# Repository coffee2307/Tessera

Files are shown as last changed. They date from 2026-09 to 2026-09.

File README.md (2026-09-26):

# Tessera

## English

### Overview

Tessera is a personal precision motion platform for compact XYZ positioning, alignment, probing, microscopy, and small-scale automation. It combines a parallel-kinematic mechanical structure with closed-loop stepper control, rotary encoders, motion planning, and a serial command interface.

The design aims to provide a low-cost and reproducible motion platform with practical sub-micron positioning capability for laboratory, research, and prototyping workflows. The software stack is divided between embedded firmware and a Python control layer so the hardware can be configured, calibrated, and operated through a clean API.

### Main features

- 3-axis XYZ motion using a parallel-kinematic mechanism
- Closed-loop control with stepper motors and encoder feedback
- Sub-micron positioning for precision alignment and inspection work
- USB serial communication with G-code-style command handling
- Firmware-side path planning and interpolation for smooth motion
- Homing and calibration routines for repeatable setup
- External tool control support for device actuation
- Open hardware and software structure for experimentation and customization

### Project architecture

The repository is organized into several functional domains:

- Mechanical design: CAD and manufacturing files in thiet_ke_co_khi/
- Electronics: PCB and schematics in dien_tu/
- Firmware: embedded C++ controller in phan_mem_nhung/bo_dieu_khien_chuyen_dong_rp/
- Python API: device communication and helper scripts in phan_mem/api_python/
- Documentation: build notes, setup guidance, and BOM in tai_lieu/

### Repository structure

- thiet_ke_co_khi/ - CAD models, assemblies, and mechanical parts
- dien_tu/ - KiCad PCB schematics and board files
- phan_mem_nhung/bo_dieu_khien_chuyen_dong_rp/ - firmware project and embedded source code
- phan_mem_nhung/bo_dieu_khien_chuyen_dong_rp/src/ - C++ firmware implementation
- phan_mem/api_python/ - Python API, utilities, and usage examples
- tai_lieu/ - technical documentation, setup references, and BOM

### Mechanical design

The mechanical platform uses a parallel geometry to achieve compact motion with high stiffness and repeatability. The structure is designed around a three-axis motion system, with linkage and ball-joint behavior tuned for controlled end-effector motion. Mechanical files are stored in the FreeCAD-based construction package and are intended to be modified and adapted for custom builds.

### Electronics design

The electronics layer includes the control board and related hardware configuration. The system relies on stepper drives, encoder interfaces, logic/control circuitry, and power distribution arranged to support the motion controller and its real-time feedback loops. These design files are located under dien_tu/ and provide the hardware reference for the embedded controller.

### Firmware architecture

The firmware is written in C++ and is organized around the real-time device controller. It implements the logic required for motion execution, servo regulation, calibration, and serial communication.

Core firmware responsibilities:

- Kinematic model: workspace and geometry calculations
- Motion controller: command execution and trajectory planning
- Servo control: feedback loops and actuator regulation
- Homing and calibration: initialization and system alignment
- Communication layer: command parsing and response handling

Main firmware components:

- phan_mem_nhung/bo_dieu_khien_chuyen_dong_rp/src/main.cpp - startup and system initialization
- phan_mem_nhung/bo_dieu_khien_chuyen_dong_rp/src/robot.cpp - coordinated device behavior
- phan_mem_nhung/bo_dieu_khien_chuyen_dong_rp/src/dieu_khien_chuyen_dong/ - path planning and movement logic
- phan_mem_nhung/bo_dieu_khien_chuyen_dong_rp/src/dieu_khien_servo/ - closed-loop control loops
- phan_mem_nhung/bo_dieu_khien_chuyen_dong_rp/src/mo_hinh_dong_hoc/ - geometry and kinematic calculations
- phan_mem_nhung/bo_dieu_khien_chuyen_dong_rp/src/hw_config.h - hardware configuration such as pin map and motor settings

### Control and communication model

The system is intended to be commanded over a serial connection. The firmware accepts motion and control instructions and returns status information to the host. This makes it compatible with higher-level control software, automation workflows, and Python-based experimentation.

Typical capabilities include:

- moving to target coordinates
- homing the axes
- enabling or disabling motors
- querying device state
- calibrating joints
- setting tool output values

### Python API

The Python layer wraps the serial connection and exposes a simplified interface for controlling the platform. It is intended to reduce the amount of low-level command handling required when testing motion, calibration, or automated procedures.

Relevant Python files:

- phan_mem/api_python/tessera_api.py
- phan_mem/api_python/vi_du_su_dung.py
- phan_mem/api_python/ve_bieu_do_hieu_chuan.py

The API generally supports:

- connection management
- homing and motion commands
- calibration routines
- device status queries
- asynchronous logging and communication feedback

### Quick start

1. Review the mechanical and electrical documentation in tai_lieu/.
2. Build the hardware according to the project instructions.
3. Adjust the hardware configuration in phan_mem_nhung/bo_dieu_khien_chuyen_dong_rp/src/hw_config.h.
4. Flash the firmware using PlatformIO.
5. Connect the device over serial.
6. Use the Python API or a terminal client to home the platform and begin motion testing.

### Example usage

```python
from phan_mem.api_python.tessera_api import TesseraInterface

api = TesseraInterface(show_communication=True, show_log_messages=True)
api.connect('/dev/ttyACM0')

api.home()
api.move_to(0.0, 0.0, 0.0, f=10)
api.move_to(3.1, 4.1, 5.9, f=26)
api.wait_for_stop()
```

### Notes

- The project is designed for open experimentation and reproducible builds.
- The firmware and mechanical system are the primary technical foundations of the repository.
- The Python layer is meant to simplify communication, testing, calibration, and operational workflows.

---

## Tiếng Việt

### Tổng quan

Tessera là một nền tảng chuyển động XYZ kiểu compact, mã nguồn mở, được thiết kế cho các nhiệm vụ căn chỉnh, dò kiểm tra, kính hiển vi và tự động hóa quy mô nhỏ. Hệ thống này kết hợp cơ cấu cơ khí song song, bộ điều khiển động cơ vòng kín, và giao diện điều khiển thân thiện với Python để tạo ra một giải pháp di chuyển chính xác với chi phí thấp và khả năng tái tạo tốt.

### Tính năng chính

- Chuyển động 3 trục XYZ theo cơ cấu song song
- Điều khiển vòng kín bằng động cơ bước và bộ mã hóa quay
- Khả năng định vị ở mức dưới micromet cho công việc căn chỉnh và kiểm tra
- Giao tiếp qua cổng serial USB với lệnh kiểu G-code
- Lập lịch đường đi và nội suy chuyển động ở phần firmware
- Chức năng homing và hiệu chuẩn để khởi tạo hệ thống lặp lại
- Hỗ trợ điều khiển đầu công cụ ngoài để kích hoạt thiết bị phụ trợ
- Cấu trúc phần cứng và phần mềm mở, dễ tùy biến và thử nghiệm

### Kiến trúc dự án

Kho mã nguồn được tổ chức theo các tầng chức năng chính:

- Thiết kế cơ khí: mô hình CAD và file gia công trong thiet_ke_co_khi/
- Điện tử: bo mạch và sơ đồ trong dien_tu/
- Firmware: bộ điều khiển nhúng C++ trong phan_mem_nhung/bo_dieu_khien_chuyen_dong_rp/
- Python API: giao tiếp thiết bị và script hỗ trợ trong phan_mem/api_python/
- Tài liệu: hướng dẫn xây dựng, thiết lập và BOM trong tai_lieu/

### Cấu trúc thư mục

- thiet_ke_co_khi/ - mô hình CAD, bộ lắp ráp và linh kiện cơ khí
- dien_tu/ - file sơ đồ PCB KiCad và board layout
- phan_mem_nhung/bo_dieu_khien_chuyen_dong_rp/ - mã nguồn firmware và dự án PlatformIO
- phan_mem_nhung/bo_dieu_khien_chuyen_dong_rp/src/ - phần triển khai firmware C++
- phan_mem/api_python/ - API Python, tiện ích và ví dụ sử dụng
- tai_lieu/ - tài liệu kỹ thuật, hướng dẫn lắp đặt và danh mục vật tư

### Thiết kế cơ khí

Cấu trúc cơ khí sử dụng hình học song song để đạt được chuyển động nhỏ gọn, cứng vững và lặp lại tốt. Hệ thống được thiết kế theo mô hình 3 trục với các liên kết và khớp cầu nhằm kiểm soát chuyển động của đầu công cụ. Các file thiết kế cơ khí nằm trong gói CAD FreeCAD và có thể được chỉnh sửa để phù hợp với từng bản dựng cụ thể.

### Thiết kế điện tử

Lớp điện tử bao gồm bo mạch điều khiển và cấu hình phần cứng tương ứng. Hệ thống dùng động cơ bước, giao diện mã hóa, mạch điều khiển logic và phân phối nguồn để hỗ trợ bộ điều khiển chuyển động và vòng phản hồi thời gian thực. Các file này nằm trong dien_tu/ và là tài liệu tham khảo cho phần firmware.

### Kiến trúc firmware

Firmware được viết bằng C++ và tổ chức theo mô hình bộ điều khiển thiết bị thời gian thực. Nó xử lý các nhiệm vụ cần thiết cho việc thực thi chuyển động, điều khiển servo, hiệu chuẩn và giao tiếp serial.

Các trách nhiệm chính của firmware:

- Mô hình động học: tính toán không gian làm việc và hình học
- Bộ điều khiển chuyển động: thực thi lệnh và lập kế hoạch quỹ đạo
- Điều khiển servo: vòng lặp phản hồi và điều chỉnh actuator
- Homing và hiệu chuẩn: khởi tạo và căn chỉnh hệ thống
- Lớp giao tiếp: phân tích lệnh và xử lý phản hồi

Những thành phần quan trọng:

- phan_mem_nhung/bo_dieu_khien_chuyen_dong_rp/src/main.cpp - khởi động và khởi tạo hệ thống
- phan_mem_nhung/bo_dieu_khien_chuyen_dong_rp/src/robot.cpp - hành vi tổng hợp của thiết bị
- phan_mem_nhung/bo_dieu_khien_chuyen_dong_rp/src/dieu_khien_chuyen_dong/ - logic lập kế hoạch đường đi
- phan_mem_nhung/bo_dieu_khien_chuyen_dong_rp/src/dieu_khien_servo/ - vòng lặp điều khiển đóng
- phan_mem_nhung/bo_dieu_khien_chuyen_dong_rp/src/mo_hinh_dong_hoc/ - tính toán hình học và động học
- phan_mem_nhung/bo_dieu_khien_chuyen_dong_rp/src/hw_config.h - cấu hình phần cứng như chân GPIO và cài đặt motor

### Mô hình điều khiển và truyền thông

Hệ thống được thiết kế để điều khiển qua kết nối serial. Firmware nhận lệnh di chuyển và điều khiển từ máy tính và gửi thông tin trạng thái trở lại. Điều này giúp hệ thống tương thích với phần mềm điều khiển cấp cao, quy trình tự động hóa và thử nghiệm dựa trên Python.

Các khả năng điển hình gồm:

- di chuyển đến tọa độ mục tiêu
- homing trục
- bật/tắt động cơ
- truy vấn trạng thái thiết bị
- hiệu chuẩn joint
- đặt giá trị đầu ra của công cụ

### Python API

Lớp Python đóng gói kết nối serial và cung cấp giao diện đơn giản để điều khiển hệ thống. Mục tiêu là giảm khối lượng xử lý lệnh mức thấp khi kiểm tra chuyển động, hiệu chuẩn hoặc quy trình tự động hóa.

Các file Python quan trọng:

- phan_mem/api_python/tessera_api.py
- phan_mem/api_python/vi_du_su_dung.py
- phan_mem/api_python/ve_bieu_do_hieu_chuan.py

API thường hỗ trợ:

- quản lý kết nối
- lệnh homing và di chuyển
- chức năng hiệu chuẩn
- truy vấn trạng thái thiết bị
- log giao tiếp và phản hồi liên tục

### Bắt đầu nhanh

1. Đọc tài liệu cơ khí và điện tử trong tai_lieu/
2. Lắp ráp phần cứng theo hướng dẫn của dự án
3. Điều chỉnh cấu hình phần cứng trong phan_mem_nhung/bo_dieu_khien_chuyen_dong_rp/src/hw_config.h
4. Nạp firmware bằng PlatformIO
5. Kết nối thiết bị qua serial
6. Dùng Python API hoặc client terminal để homing trục và bắt đầu kiểm tra chuyển động

### Ví dụ sử dụng

```python
from phan_mem.api_python.tessera_api import TesseraInterface

api = TesseraInterface(show_communication=True, show_log_messages=True)
api.connect('/dev/ttyACM0')

api.home()
api.move_to(0.0, 0.0, 0.0, f=10)
api.move_to(3.1, 4.1, 5.9, f=26)
api.wait_for_stop()
```

### Lưu ý

- Dự án này thích hợp cho thử nghiệm mở và bản dựng có thể tái sản xuất.
- Firmware và hệ thống cơ khí là nền tảng kỹ thuật chính của kho mã nguồn.
- Lớp Python nhằm đơn giản hóa giao tiếp, thử nghiệm, hiệu chuẩn và quy trình vận hành.

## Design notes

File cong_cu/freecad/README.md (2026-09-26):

# Chỉnh sửa mô hình FreeCAD Tessera

## Chạy

- Trong VS Code, chọn **Terminal > Run Task > FreeCAD: Edit Tessera**.
- Hoặc mở PowerShell tại thư mục dự án và chạy:

```powershell
& ".\cong_cu\freecad\run_freecad.ps1"
```

Script được chạy bằng Python tích hợp trong FreeCAD, không cần cài thư viện FreeCAD bằng pip. Với đối tượng `App::Link`, FreeCAD cần chạy trong GUI để có `ViewObject`; `freecadcmd.exe` ở chế độ headless không thể đổi màu riêng cho Link. Khi đó, mở FreeCAD GUI, mở Python console và chạy:

```python
exec(compile(open(r"F:\Tessera\cong_cu\freecad\edit_tessera.py", "rb").read(), r"F:\Tessera\cong_cu\freecad\edit_tessera.py", "exec"))
```

## Tệp

- Tệp đầu vào: `thiet_ke_co_khi/bo_thao_tac_vi_mo/Assembly_MicroManipulator.FCStd`
- Bản sao lưu: `thiet_ke_co_khi/bo_thao_tac_vi_mo/Assembly_MicroManipulator.backup.FCStd`
- Tệp đầu ra: `thiet_ke_co_khi/bo_thao_tac_vi_mo/Assembly_MicroManipulator_edited.FCStd`

Bản sao lưu chỉ được tạo nếu chưa tồn tại. Tệp đầu vào không bị ghi đè.

## Tùy chỉnh

Để đổi đối tượng, sửa giá trị `TARGET_NAME` trong `edit_tessera.py`.
Để đổi màu, sửa `TARGET_COLOR` bằng ba giá trị RGB từ `0` đến `255`, được chuyển thành dạng số thực khi cần. Mặc định là vàng RGB `(255, 191, 0)`.

Tệp `.FCStd` là tệp mô hình nhị phân có cấu trúc riêng; không nên sửa trực tiếp bằng trình soạn thảo văn bản. Hãy chỉnh qua FreeCAD hoặc script này.

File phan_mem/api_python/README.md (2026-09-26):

# Python API

This folder contains a lightweight Python interface for the Tessera serial protocol, plus two small example scripts:

- `vi_du_su_dung.py`: homes the device, performs a simple move, and prints device state information.
- `ve_bieu_do_hieu_chuan.py`: runs joint calibration for the first three actuators and plots the returned data.

## Requirements

Install the Python dependencies with:

```bash
python -m venv env
source env/bin/activate
pip install -r requirements.txt
```

The public API is exposed by `tessera_api.py`. The original implementation
module remains available for compatibility with existing scripts.

## Serial Port Selection

Both scripts support:

- `--list-ports`: list detected serial devices and exit
- `--port <PORT>`: explicitly select a serial port

If `--port` is not provided, the scripts try to choose a port automatically:

1. If exactly one detected device contains `Pico` in its name, that port is used.
2. Otherwise, if there is exactly one detected serial device, that port is used.
3. Otherwise, the script lists the available ports and exits.

## Running The Example Script

From this folder:

```bash
python vi_du_su_dung.py --list-ports
python vi_du_su_dung.py --port /dev/ttyACM0
```

On Windows, a typical command looks like:

```bash
python vi_du_su_dung.py --port COM3
```

## Running The Calibration Plotter

From this folder:

```bash
python ve_bieu_do_hieu_chuan.py --list-ports
python ve_bieu_do_hieu_chuan.py --port /dev/ttyACM0
```

The calibration script opens a matplotlib window with the measured calibration curves.

## Running From The Repository Root

If you prefer to run the scripts from the repository root, use:

```bash
python phan_mem/api_python/vi_du_su_dung.py --port /dev/ttyACM0
python phan_mem/api_python/ve_bieu_do_hieu_chuan.py --port /dev/ttyACM0
```

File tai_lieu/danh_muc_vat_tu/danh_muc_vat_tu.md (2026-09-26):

# Bill of Materials (BOM)

## Mechanics

| Name | Qty | Description | Comments | Suggested link | Image |
|---|-----|---|---|---|---|
| Steel ball | 12 | Ø1 mm (0.04") | Precision G10 or better. Can be sourced from small ball bearings | |
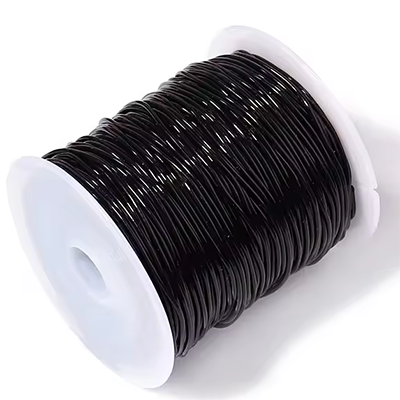
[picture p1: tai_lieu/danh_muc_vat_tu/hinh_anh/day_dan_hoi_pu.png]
Pu strech cord
| PU stretch cord | 1 m | Ø1mm | e.g. "Stretch Magic" or "Magic String" | [Aliexpress](https://www.aliexpress.us/item/3256805953910514.html)| |
| Neodym Cylinder Magnet | 70 | Ø3mm h=5 mm | N52 Grade | [NeoMagnets](https://www.buyneomagnets.com/p/3mm-dia-x-5mm-thick-n52-neodymium-rare-earth-disc-magnets-100-pack/)|
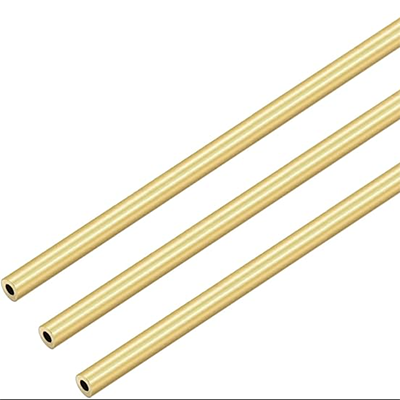
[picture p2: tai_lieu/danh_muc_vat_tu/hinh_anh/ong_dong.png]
Brass Pipe
| Brass Pipe | 1 m | OD=Ø2mm ID=Ø1 mm |  | [Amazon](https://a.co/d/1pRFmtf)| |
| M2-8 dowel | 9 | | | | |
| SHCS M2-8 | 9 | | | | |
| Set Screw M3-6 | 3 | | | | |
| FHCS M3-6 | 3 | | | | |
| FHCS M3-10 | 9 | | | | |
| FHCS M3-20 | 12  | | | | |
| Crimp Beads | 12  | | Used to affix the ends of the PU cord |  | |
## Electronics

| Name | Qty | Description | Comments | Suggested link | Image |
|---|-----|---|---|---|---|
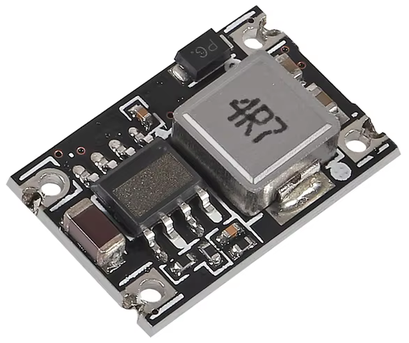
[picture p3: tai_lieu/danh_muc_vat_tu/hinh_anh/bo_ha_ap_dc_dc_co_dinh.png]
DC-DC Step Down
| DC-DC Step Down Module | 1 | 5V Fixed Output Step-Down Buck Converter |  | [Aliexpress](https://www.aliexpress.com/item/1005008257960729.html)| |
| (1N5819) OR (PMEG4010) | 1 | Diode (through-hole or SMD) |  | |
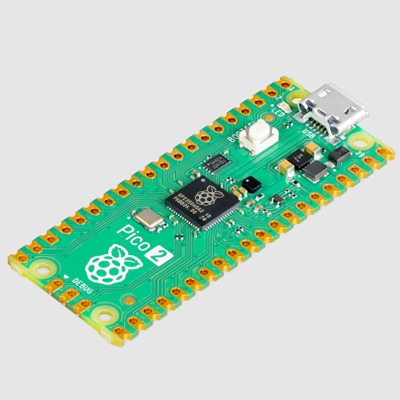
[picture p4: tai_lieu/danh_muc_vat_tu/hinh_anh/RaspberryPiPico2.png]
Raspberry Pi Pico 2
| Raspberry Pi Pico 2 | 1 | Microcontroller board |  | | |
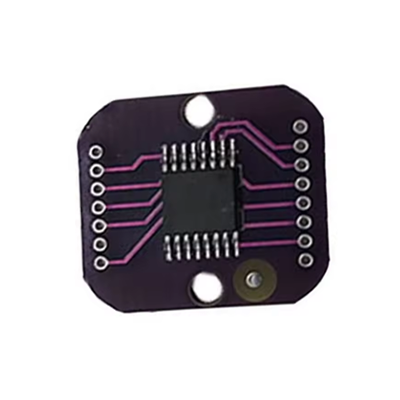
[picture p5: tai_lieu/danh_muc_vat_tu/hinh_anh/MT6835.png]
MT6835 Magnetic Encoder Module
| MT6835 Magnetic Encoder Module | 3 | Magnetic encoder |  | [Aliexpress](https://www.aliexpress.us/item/3256808005140674.html)| |
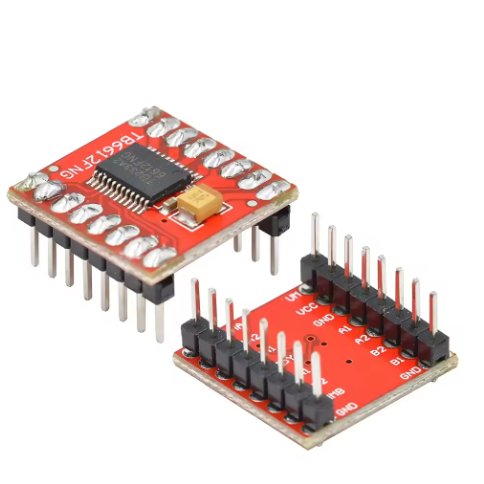
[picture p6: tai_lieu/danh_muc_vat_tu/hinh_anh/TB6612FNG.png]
TB6612FNG Driver
| TB6612FNG Driver | 3 | |  | [Aliexpress](https://www.aliexpress.us/item/3256806060073976.html)| |
| 470 µF Electrolytic Capacitor | 3 | > 100 µF | anything > 100µF will work well | |
| 10 µF Ceramic Capacitor 0603 | 3 | Optional |  | |
| 4.7 k Resistor 0603 | 2 | Optional |  | |
| NEMA 17 Stepper Motor | 3 | Body ≤ 38 mm | Body length <= 38mm | |
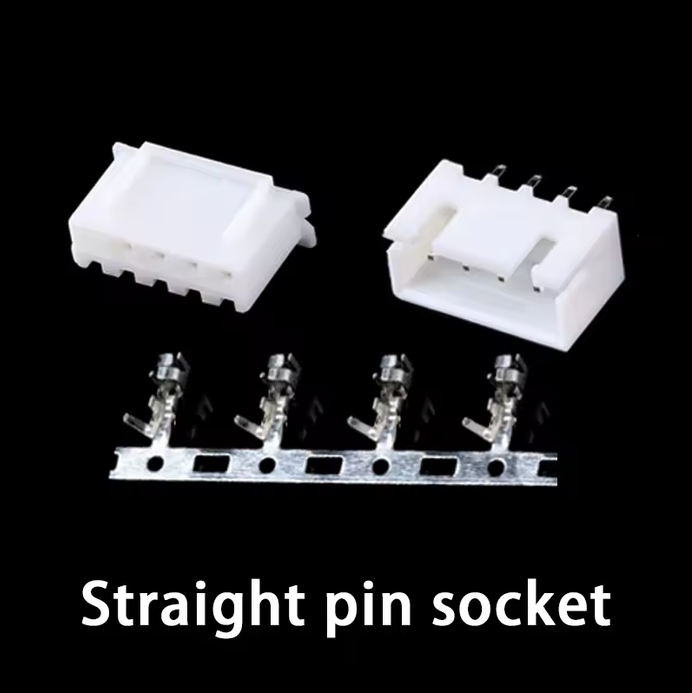
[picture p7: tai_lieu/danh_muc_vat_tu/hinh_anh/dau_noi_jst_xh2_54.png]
JST XH2.54 Connector
| JST XH2.54 4P connector | 3 | 4P Housing & Header 2.54mm pitch | J1, J2, J3 (motors) | [Aliexpress](https://www.aliexpress.com/item/1005007080333485.html?spm=a2g0o.order_list.order_list_main.53.3d5d1802JZg5Wb) |  |
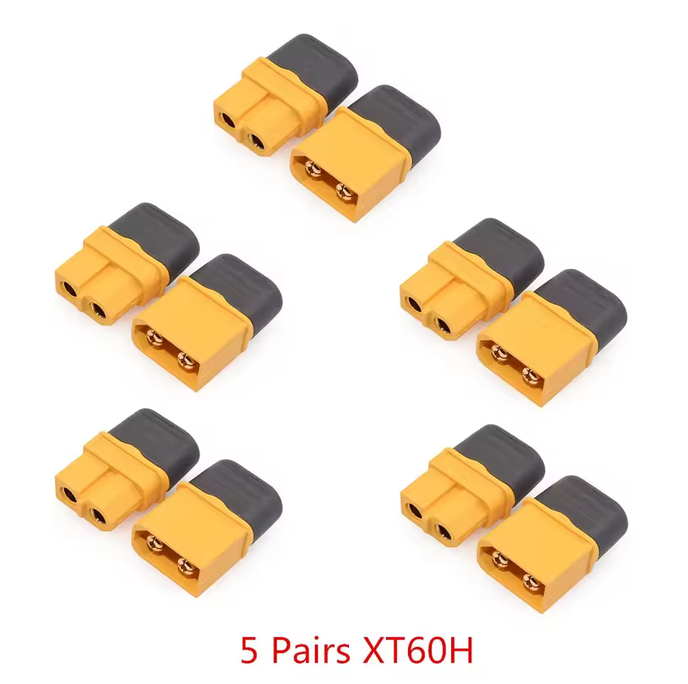
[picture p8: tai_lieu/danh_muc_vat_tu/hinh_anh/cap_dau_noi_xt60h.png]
XT60H Connector
| XT60H Connector | 1 | 2P Male & Female pair 7.5mm pitch | Power connector | [Aliexpress](https://www.aliexpress.com/item/1005007605928815.html?spm=a2g0o.order_list.order_list_main.409.3d5d1802JZg5Wb) |  |
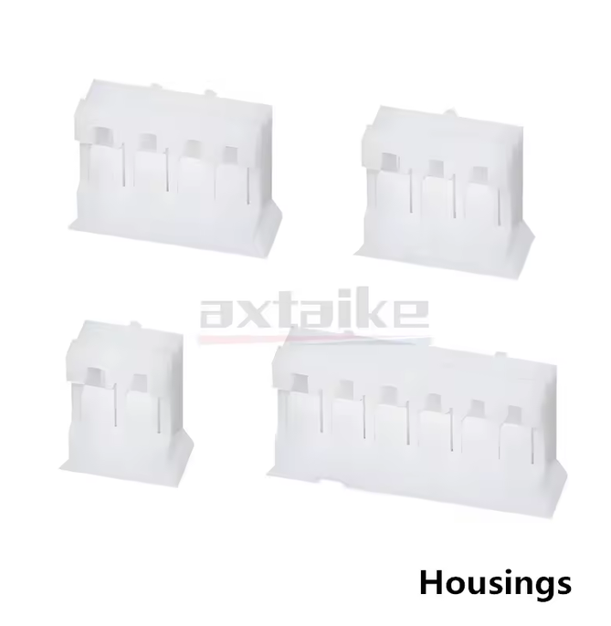
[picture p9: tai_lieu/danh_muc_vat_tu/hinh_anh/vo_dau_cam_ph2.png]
PH2.0 Housings
| PH2.0 4P Housing <br> PH2.0 8P Housing | 1 <br> 1 | 4P 2mm pitch Housing <br> 8P 2mm pitch Housing | J5 (tool/I2C)<br> J4 (encoders) | [Aliexpress](https://www.aliexpress.com/item/1005010491403413.html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) |  |
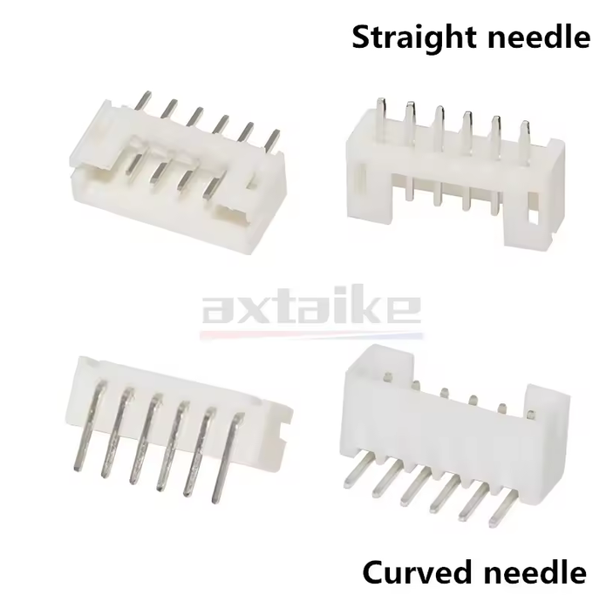
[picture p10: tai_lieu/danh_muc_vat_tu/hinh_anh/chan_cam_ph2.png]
PH2.0 Headers
| PH2.0 4P Header <br> PH2.0 8P Header | 1 <br> 1 | 4P 2mm pitch Header <br> 8P 2mm pitch Header | J5 (tool/I2C) <br> J4 (encoders) | [Aliexpress](https://www.aliexpress.com/item/1005010491403413.html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) |  |
## PCBs

| Name | Qty | Description | Comments | Image |
| --- | --- | --- | --- | ----- |
| Control Board | 1 | | | |
| balljoint_plate_pcb | 6 | | | |

## 3D Printing

| Name | Qty | Description | Comments | Image |
| --- | --- | --- | --- | --- |
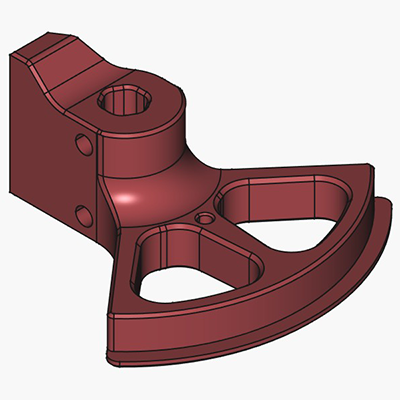
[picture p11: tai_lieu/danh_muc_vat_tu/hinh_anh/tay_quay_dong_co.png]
Motor Horn
| Motor Horn | 3 | | 0.4 mm+ nozzle may require post-processing |  |
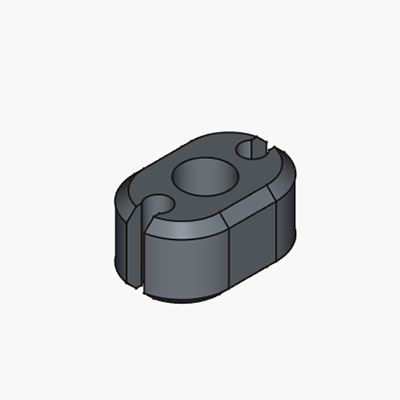
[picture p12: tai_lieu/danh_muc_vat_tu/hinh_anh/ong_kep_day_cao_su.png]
Rubber Band Collet
| RubberBandCollet | 12  | | 0.4 mm nozzle, 0.1mm Layer height + may require post-processing |  |
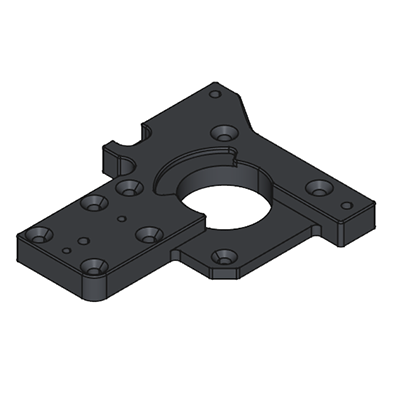
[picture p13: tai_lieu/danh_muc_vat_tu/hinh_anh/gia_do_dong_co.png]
Motor Mount
| Motor Mount | 3 | | |  |
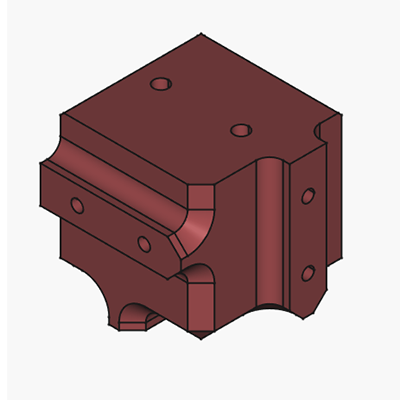
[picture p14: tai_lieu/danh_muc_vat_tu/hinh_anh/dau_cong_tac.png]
End Effector
| End Effector | 1 | | |  |
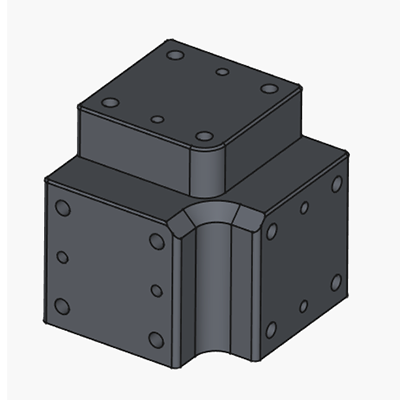
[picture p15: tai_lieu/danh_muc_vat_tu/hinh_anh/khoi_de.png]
Base Block
| Base Block | 1 | | |  |

# Tool - Rod Sharpener

## 3D Printing

| Name | Qty | Description | Comments | Image |
| --- | --- | --- | --- | ----- |
| Rod Guide | 1 | | | |
| Blade Carrier | 1 | | | |

# Tool - Rod Length Setting Press

## PCBs

| Name | Qty | Description | Comments | Image |
| --- | --- | --- | --- | ----- |
| ball_alignment_disc_pcb | 1 | | | |

## 3D Printing 

| Name | Qty | Description | Comments | Image |
| --- | --- | --- | --- | ----- |
| RodGrindingJigA | 1 | | | |
| RodGrindingJigB | 1 | | | |
| RodGuide | 1 | | | |
| RodCollet | 2 | | | |
| CaliperClamp | 2 | | | |

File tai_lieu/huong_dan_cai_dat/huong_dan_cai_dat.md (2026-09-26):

# Setup Guide

This guide walks you through the setup of your new **Tessera** device.

## Checklist for New Devices

1. **Was the mechanical limit pin added to the rotor?**  
   This pin is required for proper homing of the device.

    <div style="display: flex;">
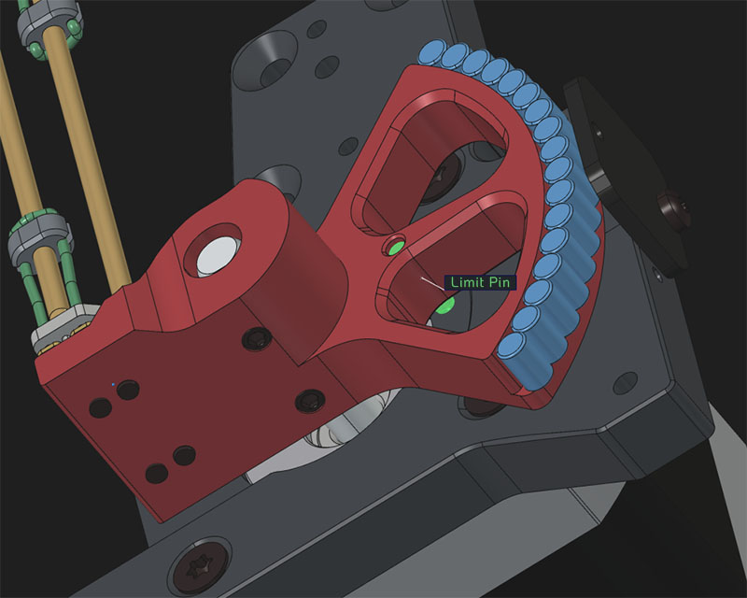
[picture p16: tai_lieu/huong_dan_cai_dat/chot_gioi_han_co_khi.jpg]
        
    </div>

2. **Are the screws that secure the rotor to the motor shaft installed?**  
   If the rotor is not firmly attached, it may slip imperceptibly during homing or other movements, leading to problems during calibration and homing.

3. **Is the homing direction correct?**  
   During the homing command (`G28`), the end effector should move toward the base.  
   If it moves in the opposite direction, rewire the motor to reverse its direction.

   <div style="display: flex;">
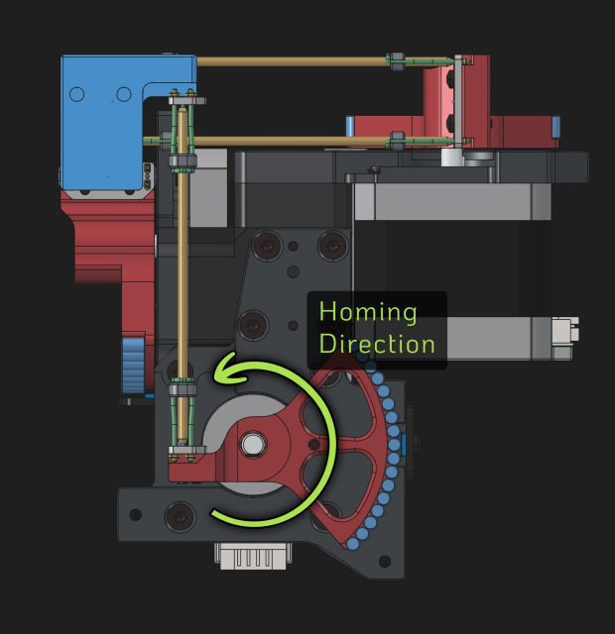
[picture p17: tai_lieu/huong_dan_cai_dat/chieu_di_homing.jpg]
    
   </div>

## Calibration and Checking the Encoders

You can use the calibration plotter to check if your encoders are working as expected.
On the left you see a good calibration on the right a bad calibration.

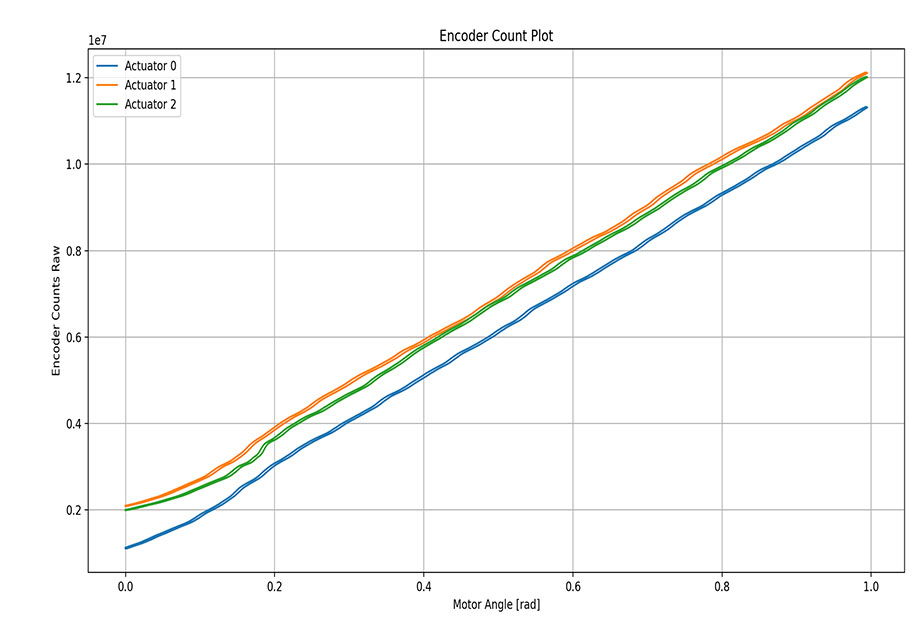
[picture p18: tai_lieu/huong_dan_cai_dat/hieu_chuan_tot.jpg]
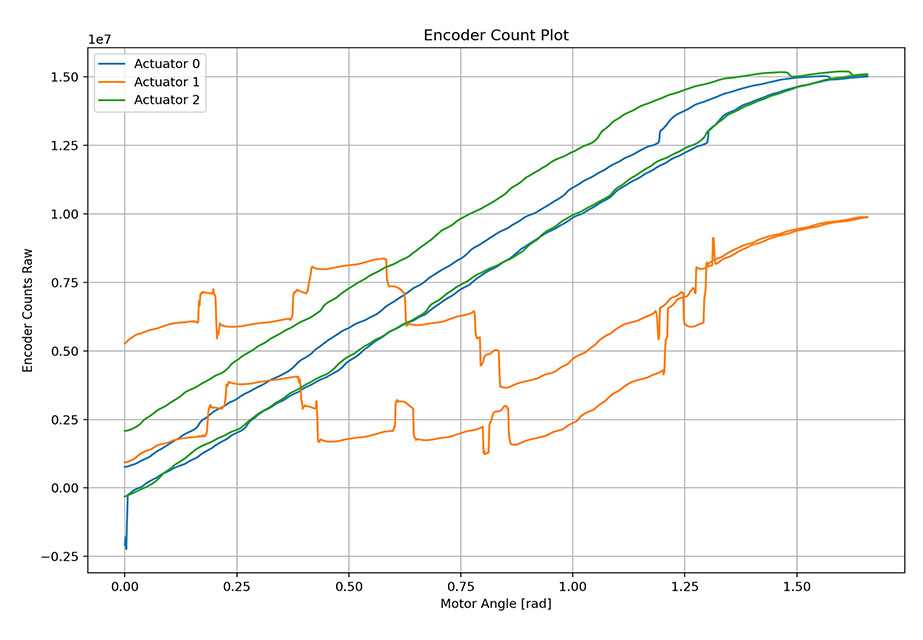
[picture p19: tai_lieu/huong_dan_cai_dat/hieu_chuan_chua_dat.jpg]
|  |  |
:--:|:--:
| **Good calibration** | **Bad calibration** |

THIS DOCUMENT IS UNFINISHED AND WORK IN PROGRESS...

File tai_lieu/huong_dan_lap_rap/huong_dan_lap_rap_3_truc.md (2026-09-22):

# Open MircoManipulator 3DOF - Build Guide

This document shall provide an easy to follow build guide and help with material selection like glues/magnets and so on.
The following structure is just a placeholder, feel free to contribute...

## Introduction

## Bill of Materials

## Components
### Mechanical Parts
### Magnet Selection

## Balljoints
## Assembly

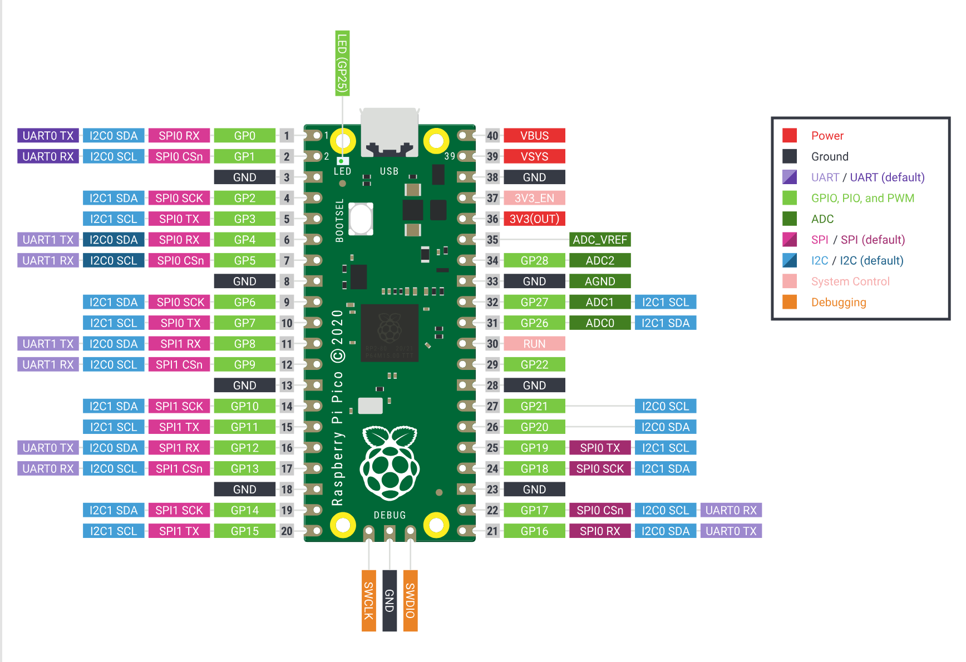
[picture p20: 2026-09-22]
phan_mem_nhung/bo_dieu_khien_chuyen_dong_rp/Rp2350-Pico_Pinout.png

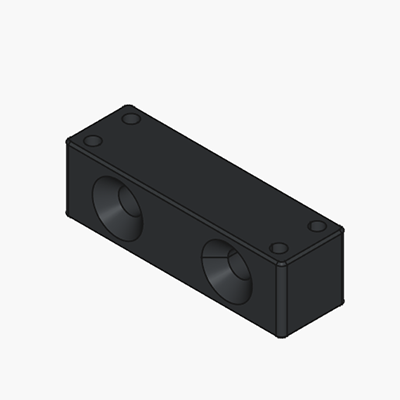
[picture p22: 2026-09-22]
tai_lieu/danh_muc_vat_tu/hinh_anh/gia_do_khop_cau.png

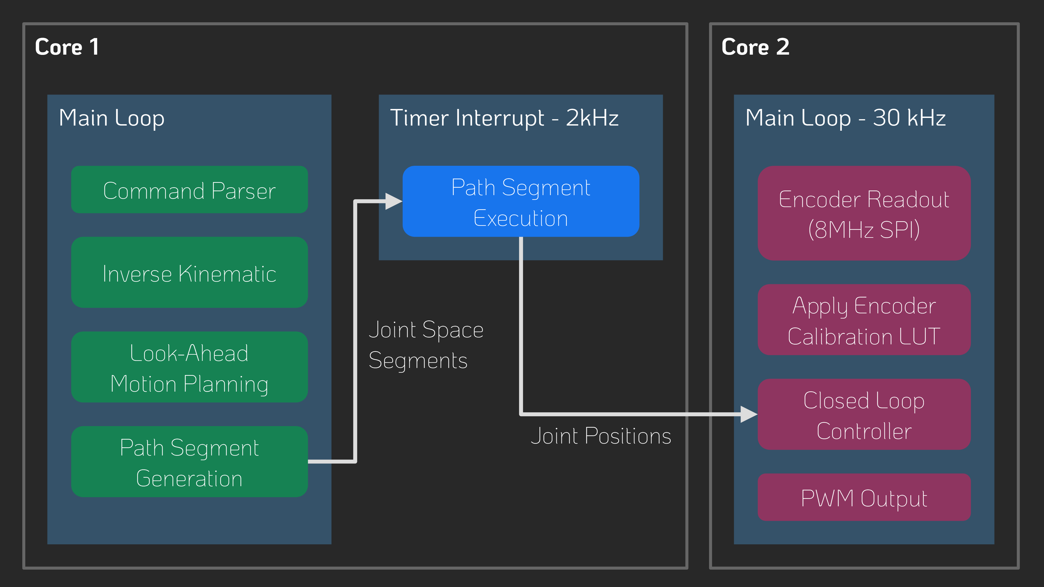
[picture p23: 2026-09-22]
tai_lieu/tai_lieu_firmware/tong_quan_firmware.png

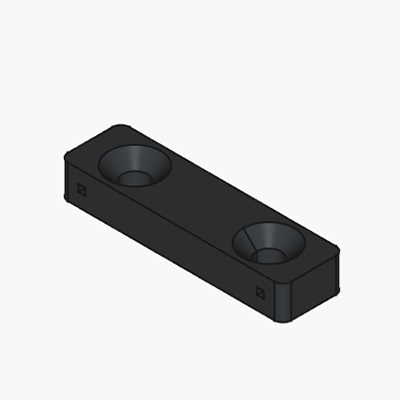
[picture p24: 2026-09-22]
tai_lieu/danh_muc_vat_tu/hinh_anh/gia_do_day_dan_dan_hoi.png

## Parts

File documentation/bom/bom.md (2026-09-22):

# Bill of Materials (BOM)

## Mechanics

| Name | Qty | Description | Comments | Suggested link | Image |
|---|-----|---|---|---|---|
| Steel ball | 12 | Ø1 mm (0.04") | Precision G10 or better. Can be sourced from small ball bearings | |
| PU stretch cord | 1 m | Ø1mm | e.g. "Stretch Magic" or "Magic String" | [Aliexpress](https://www.aliexpress.us/item/3256805953910514.html)| Pu strech cord|
| Neodym Cylinder Magnet | 70 | Ø3mm h=5 mm | N52 Grade | [NeoMagnets](https://www.buyneomagnets.com/p/3mm-dia-x-5mm-thick-n52-neodymium-rare-earth-disc-magnets-100-pack/)|
| Brass Pipe | 1 m | OD=Ø2mm ID=Ø1 mm |  | [Amazon](https://a.co/d/1pRFmtf)| Brass Pipe|
| M2-8 dowel | 9 | | | | |
| SHCS M2-8 | 9 | | | | |
| Set Screw M3-6 | 3 | | | | |
| FHCS M3-6 | 3 | | | | |
| FHCS M3-10 | 9 | | | | |
| FHCS M3-20 | 12  | | | | |
| Crimp Beads | 12  | | Used to affix the ends of the PU cord |  | |
## Electronics

| Name | Qty | Description | Comments | Suggested link | Image |
|---|-----|---|---|---|---|
| DC-DC Step Down Module | 1 | 5V Fixed Output Step-Down Buck Converter |  | [Aliexpress](https://www.aliexpress.com/item/1005008257960729.html)| DC-DC Step Down|
| (1N5819) OR (PMEG4010) | 1 | Diode (through-hole or SMD) |  | |
| Raspberry Pi Pico 2 | 1 | Microcontroller board |  | | Raspberry Pi Pico 2|
| MT6835 Magnetic Encoder Module | 3 | Magnetic encoder |  | [Aliexpress](https://www.aliexpress.us/item/3256808005140674.html)| MT6835 Magnetic Encoder Module|
| TB6612FNG Driver | 3 | |  | [Aliexpress](https://www.aliexpress.us/item/3256806060073976.html)| TB6612FNG Driver|
| 470 µF Electrolytic Capacitor | 3 | > 100 µF | anything > 100µF will work well | |
| 10 µF Ceramic Capacitor 0603 | 3 | Optional |  | |
| 4.7 k Resistor 0603 | 2 | Optional |  | |
| NEMA 17 Stepper Motor | 3 | Body ≤ 38 mm | Body length <= 38mm | |
| JST XH2.54 4P connector | 3 | 4P Housing & Header 2.54mm pitch | J1, J2, J3 (motors) | [Aliexpress](https://www.aliexpress.com/item/1005007080333485.html?spm=a2g0o.order_list.order_list_main.53.3d5d1802JZg5Wb) | JST XH2.54 Connector |
| XT60H Connector | 1 | 2P Male & Female pair 7.5mm pitch | Power connector | [Aliexpress](https://www.aliexpress.com/item/1005007605928815.html?spm=a2g0o.order_list.order_list_main.409.3d5d1802JZg5Wb) | XT60H Connector |
| PH2.0 4P Housing <br> PH2.0 8P Housing | 1 <br> 1 | 4P 2mm pitch Housing <br> 8P 2mm pitch Housing | J5 (tool/I2C)<br> J4 (encoders) | [Aliexpress](https://www.aliexpress.com/item/1005010491403413.html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) | PH2.0 Housings |
| PH2.0 4P Header <br> PH2.0 8P Header | 1 <br> 1 | 4P 2mm pitch Header <br> 8P 2mm pitch Header | J5 (tool/I2C) <br> J4 (encoders) | [Aliexpress](https://www.aliexpress.com/item/1005010491403413.html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) | PH2.0 Headers |
## PCBs

| Name | Qty | Description | Comments | Image |
| --- | --- | --- | --- | ----- |
| Control Board | 1 | | | |
| balljoint_plate_pcb | 6 | | | |

## 3D Printing

| Name | Qty | Description | Comments | Image |
| --- | --- | --- | --- | --- |
| Motor Horn | 3 | | 0.4 mm+ nozzle may require post-processing | Motor Horn |
| RubberBandCollet | 12  | | 0.4 mm nozzle, 0.1mm Layer height + may require post-processing | Rubber Band Collet |
| Motor Mount | 3 | | | Motor Mount |
| End Effector | 1 | | | End Effector |
| Base Block | 1 | | | Base Block |

# Tool - Rod Sharpener

## 3D Printing

| Name | Qty | Description | Comments | Image |
| --- | --- | --- | --- | ----- |
| Rod Guide | 1 | | | |
| Blade Carrier | 1 | | | |

# Tool - Rod Length Setting Press

## PCBs

| Name | Qty | Description | Comments | Image |
| --- | --- | --- | --- | ----- |
| ball_alignment_disc_pcb | 1 | | | |

## 3D Printing 

| Name | Qty | Description | Comments | Image |
| --- | --- | --- | --- | ----- |
| RodGrindingJigA | 1 | | | |
| RodGrindingJigB | 1 | | | |
| RodGuide | 1 | | | |
| RodCollet | 2 | | | |
| CaliperClamp | 2 | | | |

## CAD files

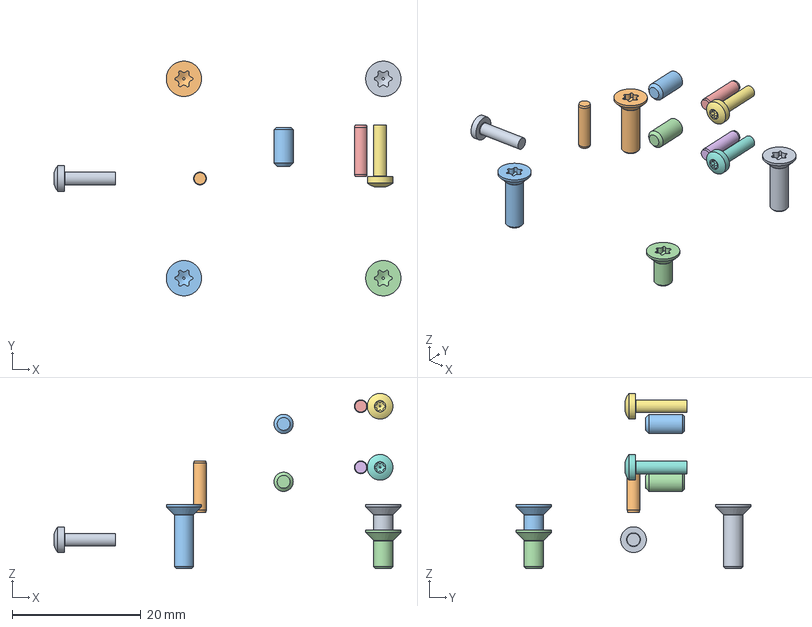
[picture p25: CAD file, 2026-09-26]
thiet_ke_co_khi/bo_thao_tac_vi_mo/Assembly_Actuator.FCStd
53.9 x 36.5 x 27.2 mm
M3x10-Screw x 2
M3x10-Screw008 x 2
M3x10-Screw009 x 2
M3x6-Screw x 2
2 mmx8-Pin x 2
2 mmx8-Pin012 x 2
M2x8-Screw x 2
M2x8-Screw009 x 2
M2x8-Screw004 x 2
2 mmx8-Pin011 x 2
M3x6-Screw003 x 2
M3x6-Screw004 x 2

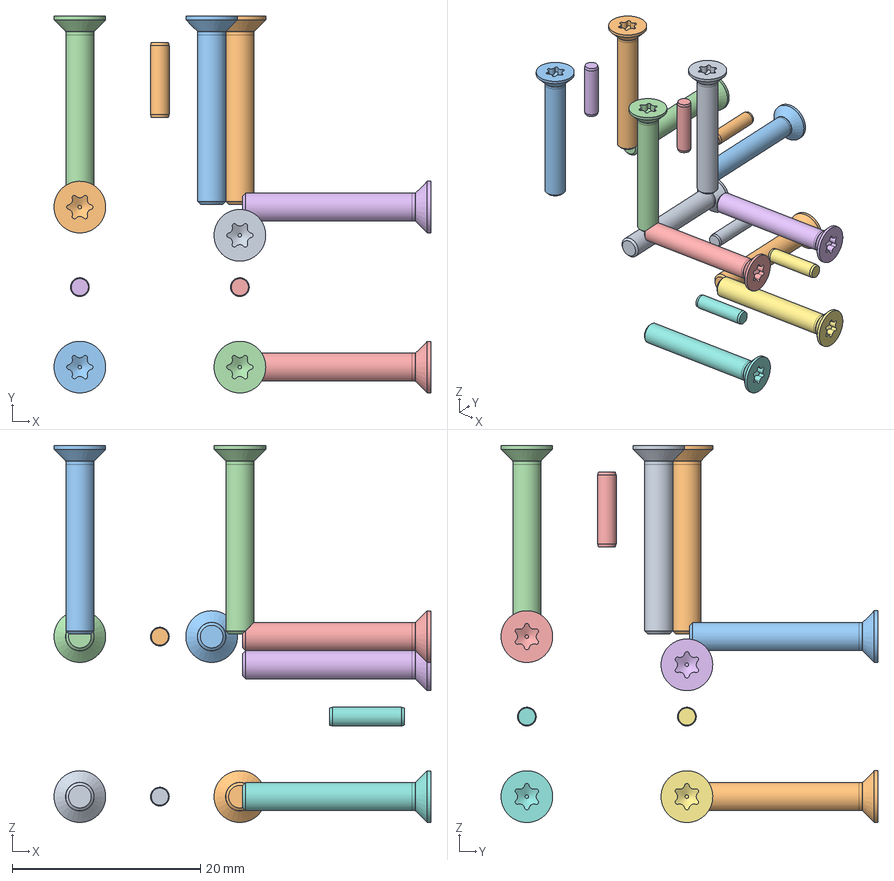
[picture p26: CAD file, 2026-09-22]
thiet_ke_co_khi/bo_thao_tac_vi_mo/Assembly_MicroManipulator.FCStd
40.0 x 40.0 x 40.0 mm
M3x20-Screw x 2
M3x20-Screw281 x 2
M3x20-Screw282 x 2
M3x20-Screw283 x 2
M3x20-Screw277 x 2
M3x20-Screw278 x 2
M3x20-Screw279 x 2
M3x20-Screw280 x 2
M3x20-Screw262 x 2
M3x20-Screw263 x 2
M3x20-Screw264 x 2
M3x20-Screw265 x 2
2 mmx8-Pin027 x 2
2 mmx8-Pin028 x 2
2 mmx8-Pin029 x 2
2 mmx8-Pin030 x 2
2 mmx8-Pin031 x 2
2 mmx8-Pin032 x 2

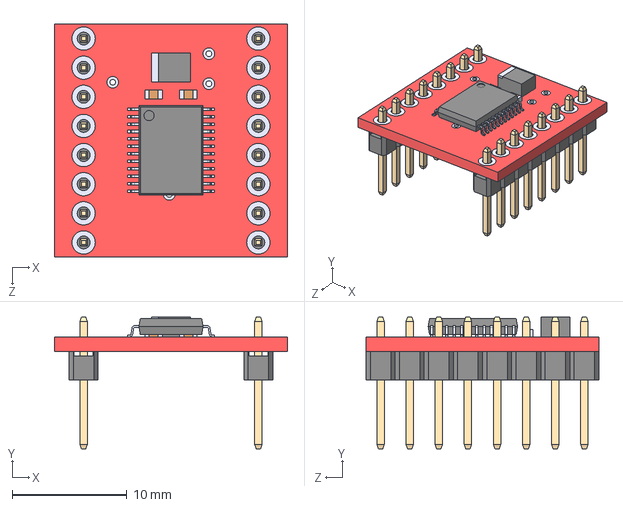
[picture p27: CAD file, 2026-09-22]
dien_tu/bo_mach_dieu_khien/thu_vien/ROB-14450/ROB-14450.step
20.3 x 11.5 x 20.3 mm

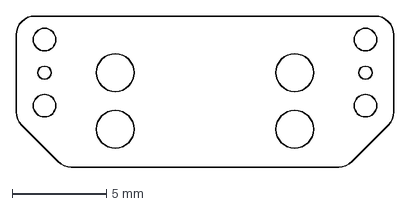
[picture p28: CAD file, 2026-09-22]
thiet_ke_co_khi/bo_thao_tac_vi_mo/pcb_tam_khop_cau/BallJointPlate-Contour.dxf
20.0 x 8.00 mm

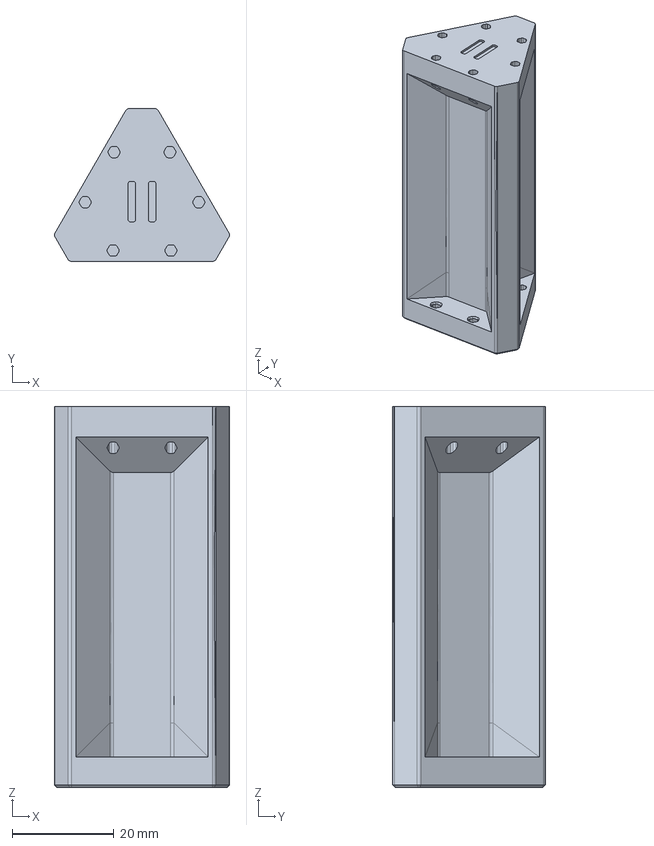
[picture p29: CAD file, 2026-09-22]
thiet_ke_co_khi/dung_cu_co_khi/dung_cu_dap_noi_thanh/bo_ep_chinh_chieu_dai_thanh/RodGrindingJig_B.FCStd
34.5 x 30.1 x 75.0 mm

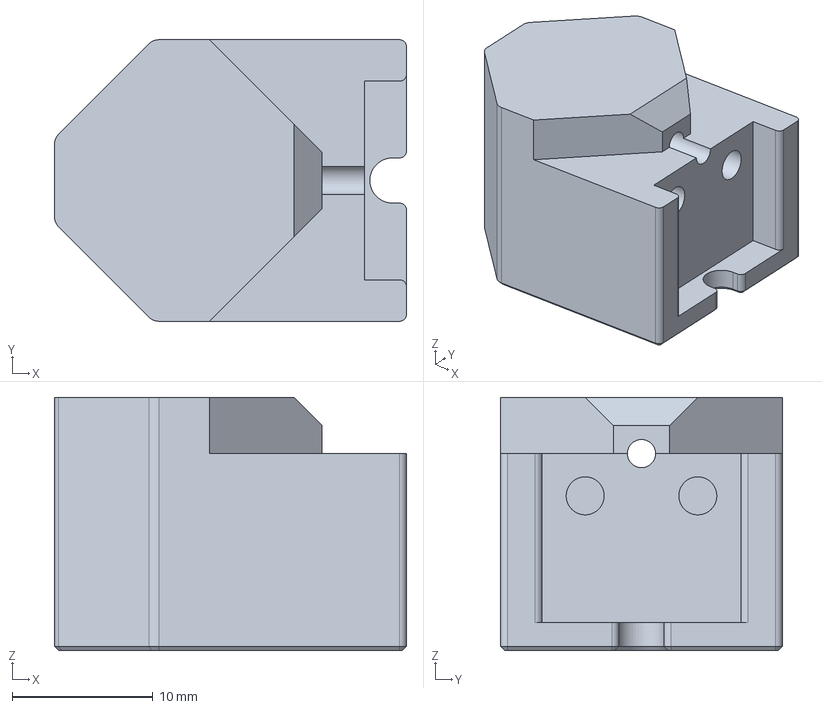
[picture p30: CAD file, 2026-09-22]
thiet_ke_co_khi/dung_cu_co_khi/dung_cu_dap_noi_thanh/dung_cu_ma_nhon_thanh/RodGuide.FCStd
25.0 x 20.0 x 18.0 mm

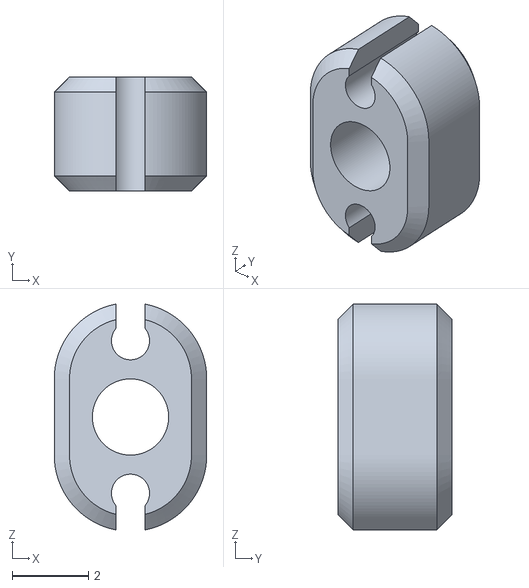
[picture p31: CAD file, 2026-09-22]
thiet_ke_co_khi/stl_in_3d_v4/chi_tiet_may/ong_kep_day_cao_su.stl
4.00 x 3.00 x 5.93

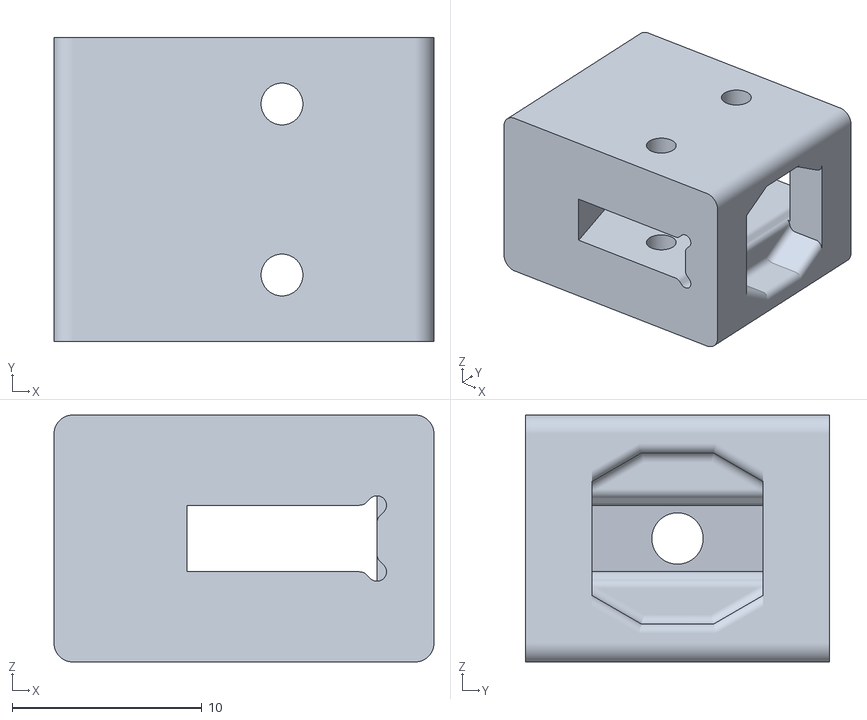
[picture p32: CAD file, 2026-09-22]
thiet_ke_co_khi/stl_in_3d_v4/dung_cu/bo_ep_chinh_chieu_dai_thanh/kep_thuoc_cap.stl
20.0 x 16.0 x 13.0

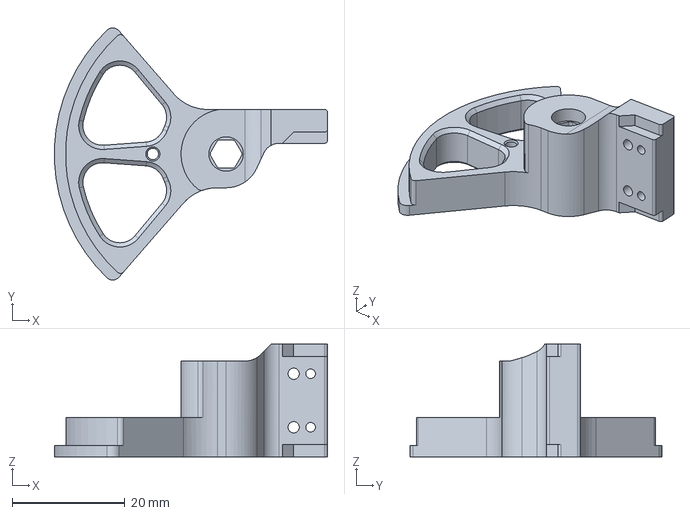
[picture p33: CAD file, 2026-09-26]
thiet_ke_co_khi/bo_thao_tac_vi_mo/MotorHorn.FCStd
48.5 x 44.7 x 20.0 mm

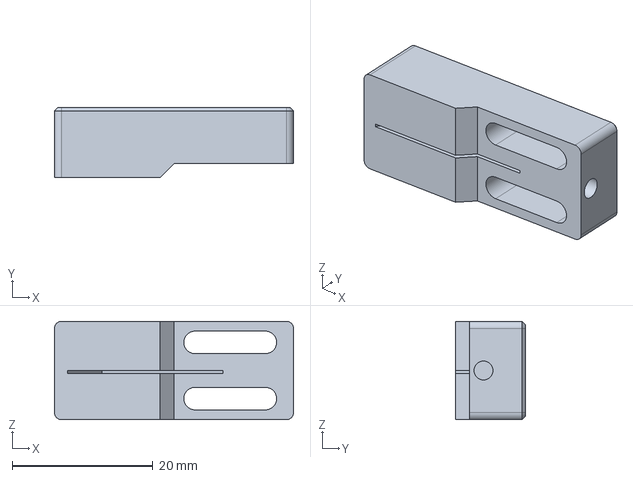
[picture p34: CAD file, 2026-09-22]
thiet_ke_co_khi/dung_cu_co_khi/dung_cu_dap_noi_thanh/dung_cu_ma_nhon_thanh/BladeCarrier.FCStd
34.0 x 10.0 x 14.0 mm

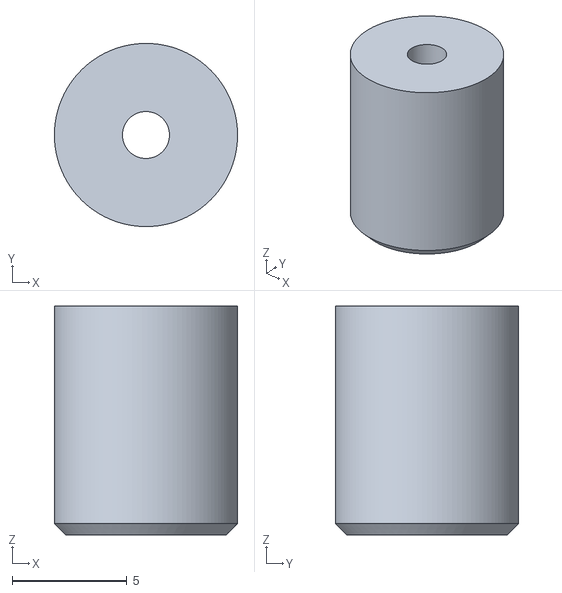
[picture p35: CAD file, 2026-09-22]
thiet_ke_co_khi/stl_in_3d_v4/dung_cu/bo_ep_chinh_chieu_dai_thanh/ong_kep_thanh.stl
8.00 x 8.00 x 10.0

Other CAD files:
thiet_ke_co_khi/bo_thao_tac_vi_mo/Assembly_LinkageUnit.FCStd
thiet_ke_co_khi/bo_thao_tac_vi_mo/Assembly_EndEffector.FCStd
thiet_ke_co_khi/bo_thao_tac_vi_mo/Assembly_BallJointPlate.FCStd
thiet_ke_co_khi/stl_in_3d_v4/dung_cu/dung_cu_ma_nhon_thanh/ong_dan_thanh.stl
thiet_ke_co_khi/dung_cu_co_khi/dung_cu_dap_noi_thanh/bo_ep_chinh_chieu_dai_thanh/RodGrindingJig_A.FCStd
thiet_ke_co_khi/stl_in_3d_v4/chi_tiet_may/tay_quay_dong_co.stl
thiet_ke_co_khi/bo_thao_tac_vi_mo/BallJointPlate.FCStd
thiet_ke_co_khi/bo_thao_tac_vi_mo/BaseBlock.FCStd
thiet_ke_co_khi/bo_thao_tac_vi_mo/CrimpBead.FCStd
thiet_ke_co_khi/bo_thao_tac_vi_mo/EncoderMagnet.FCStd
thiet_ke_co_khi/bo_thao_tac_vi_mo/EncoderMagnetArray.FCStd
thiet_ke_co_khi/bo_thao_tac_vi_mo/EndEffector.FCStd
thiet_ke_co_khi/bo_thao_tac_vi_mo/JointBall.FCStd
thiet_ke_co_khi/bo_thao_tac_vi_mo/LinkageRod.FCStd
thiet_ke_co_khi/bo_thao_tac_vi_mo/MT6835.FCStd
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

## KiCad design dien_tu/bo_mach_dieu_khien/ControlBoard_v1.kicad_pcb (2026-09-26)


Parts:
A1: RaspberryPi_Pico; RaspberryPi_Pico_Common_Unspecified
C1, C2, C3: C_Polarized; CP_Radial_D8.0mm_P3.50mm
C4, C5, C6: C; C_0603_1608Metric_Pad1.08x0.95mm_HandSolder
D1: 1N5819; D_DO-41_SOD81_P10.16mm_Horizontal
D2: PMEG4010; D_SOD-123F
H1, H2, H3, H4, H5, H6: MountingHole_Pad; MountingHole_2.7mm_M2.5_Pad_Via
J1: Motor1; PinHeader_1x04_P2.54mm_Vertical
J2: Motor2; PinHeader_1x04_P2.54mm_Vertical
J3: Motor3; PinHeader_1x04_P2.54mm_Vertical
J4: Encoder; JST_PH_B8B-PH-K_1x08_P2.00mm_Vertical
J5: I2C; JST_PH_B4B-PH-K_1x04_P2.00mm_Vertical
J7: Power; AMASS_XT60-M_1x02_P7.20mm_Vertical
R1, R2: 4K7; R_0603_1608Metric_Pad0.98x0.95mm_HandSolder
U1, U2, U3: ROB-14450; MODULE_ROB-14450; PARTREV 11-13-17
U4: DCDC_Converter; DCDC_17mmx12mm

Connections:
+3.3V: A1.36 (3V3), C4.1, C5.1, C6.1, J4.2, J5.4, R1.1, R2.1, U1.2 (VCC), U2.2 (VCC), U3.2 (VCC)
+5V: A1.39 (VSYS), D1.1 (K), D2.1 (K)
+12V: C1.1, C2.1, C3.1, J7.2, U1.1 (VM), U2.1 (VM), U3.1 (VM), U4.2 (IN+)
/Encoder1_CS: A1.26 (GPIO20), J4.6
/Encoder2_CS: A1.27 (GPIO21), J4.7
/Encoder3_CS: A1.29 (GPIO22), J4.8
/Encoder_MISO: A1.1 (GPIO0), J4.4
/Encoder_MOSI: A1.5 (GPIO3), J4.3
/Encoder_SCK: A1.4 (GPIO2), J4.5
/I2C_SCL: A1.21 (GPIO16), J5.3, R1.2
/I2C_SDA: A1.22 (GPIO17), J5.2, R2.2
/Motor1_A1: A1.17 (GPIO13), U1.14 (AI1)
/Motor1_A2: A1.16 (GPIO12), U1.15 (AI2)
/Motor1_B1: A1.19 (GPIO14), U1.12 (BI1)
/Motor1_B2: A1.20 (GPIO15), U1.11 (BI2)
/Motor2_A1: A1.12 (GPIO9), U2.14 (AI1)
/Motor2_A2: A1.11 (GPIO8), U2.15 (AI2)
/Motor2_B1: A1.14 (GPIO10), U2.12 (BI1)
/Motor2_B2: A1.15 (GPIO11), U2.11 (BI2)
/Motor3_A1: A1.7 (GPIO5), U3.14 (AI1)
/Motor3_A2: A1.6 (GPIO4), U3.15 (AI2)
/Motor3_B1: A1.9 (GPIO6), U3.12 (BI1)
/Motor3_B2: A1.10 (GPIO7), U3.11 (BI2)
/MotorEN: A1.24 (GPIO18), U1.13 (STBY), U2.13 (STBY), U3.13 (STBY)
/MotorPWM: A1.25 (GPIO19), U1.10 (PWMB), U1.16 (PWMA), U2.10 (PWMB), U2.16 (PWMA), U3.10 (PWMB), U3.16 (PWMA)
GND: A1.3 (GND), A1.8 (GND), A1.13 (GND), A1.18 (GND), A1.23 (GND), A1.28 (GND), A1.33 (AGND), A1.38 (GND), C1.2, C2.2, C3.2, C4.2, C5.2, C6.2, J4.1, J5.1, J7.1, U1.3 (GND), U1.8 (GND), U1.9 (GND), U2.3 (GND), U2.8 (GND), U2.9 (GND), U3.3 (GND), U3.8 (GND), U3.9 (GND), U4.1 (IN-), U4.3 (OUT-)
unnamed: D1.2 (A), D2.2 (A), U4.4 (OUT+)
unnamed: J1.1, U1.7 (B01)
unnamed: J1.2, U1.6 (B02)
unnamed: J1.3, U1.5 (A02)
unnamed: J1.4, U1.4 (A01)
unnamed: J2.1, U2.7 (B01)
unnamed: J2.2, U2.6 (B02)
unnamed: J2.3, U2.5 (A02)
unnamed: J2.4, U2.4 (A01)
unnamed: J3.1, U3.7 (B01)
unnamed: J3.2, U3.6 (B02)
unnamed: J3.3, U3.5 (A02)
unnamed: J3.4, U3.4 (A01)

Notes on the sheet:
PWM pin is usually not used in this application and is always 1
Motor Driver 2
Power
Interfaces
Motor Driver 1
Motor Driver 3
Mechanical
Populate one of these diodes.
Micro Controller



Board: 2 copper layers, 64.0 x 85.0 mm, 27 parts (6 on the bottom side), 39 nets.

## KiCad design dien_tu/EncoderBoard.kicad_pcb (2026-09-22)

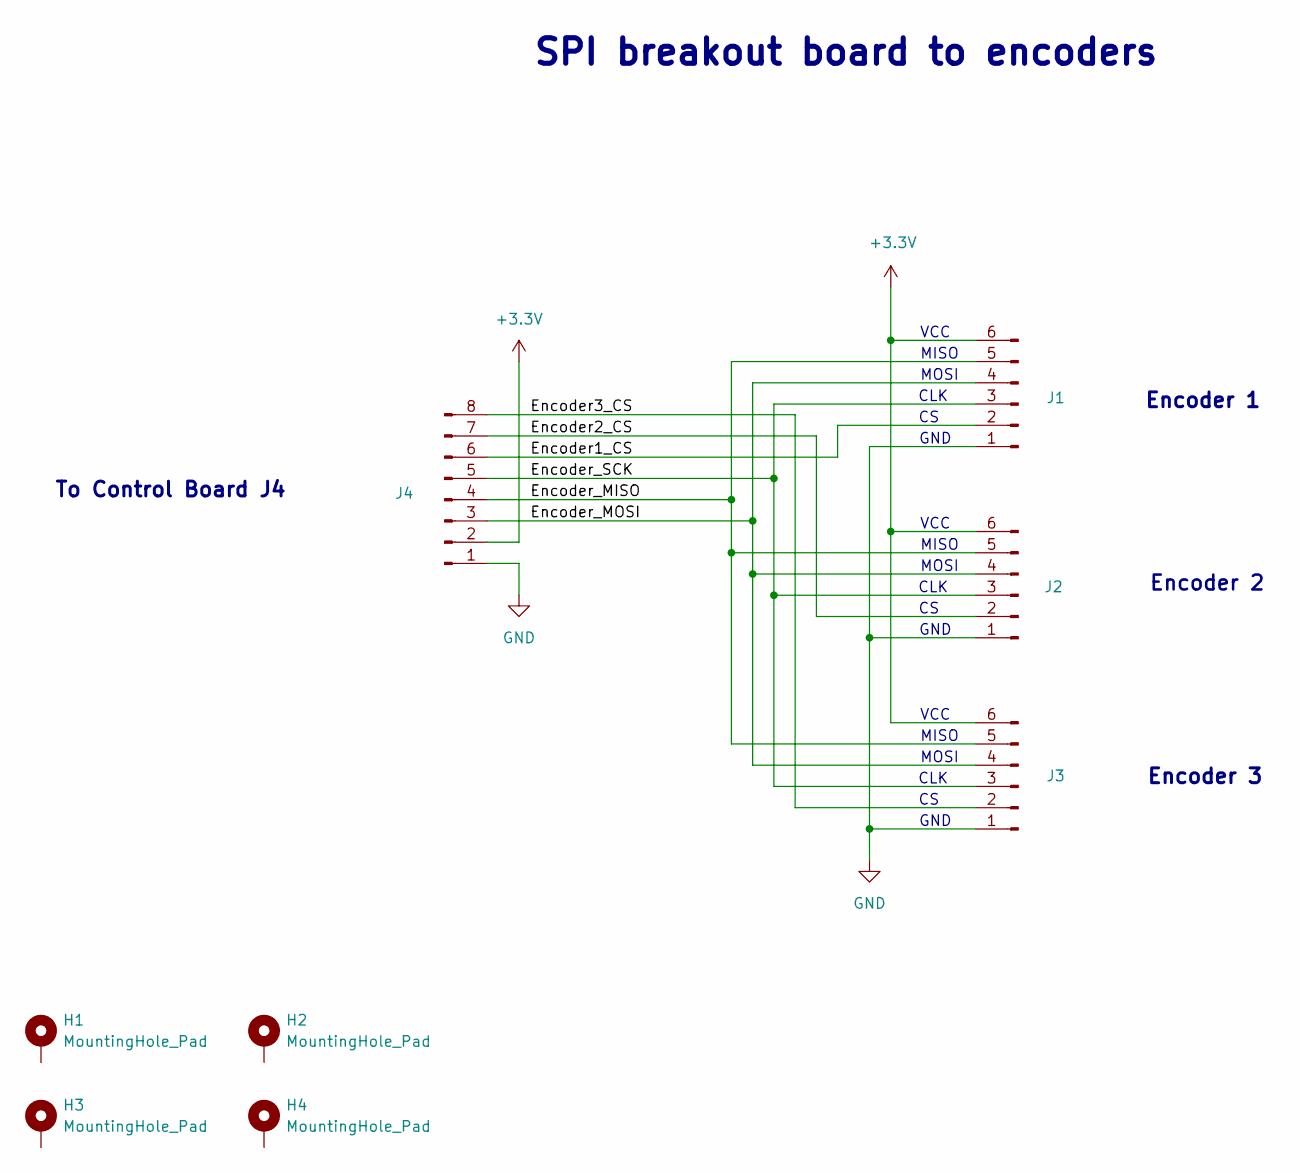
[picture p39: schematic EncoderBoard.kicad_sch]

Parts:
H1, H2, H3, H4: MountingHole_Pad; MountingHole_2.7mm_M2.5_Pad_Via
J1, J2, J3: Conn_01x06_Pin; JST_PH_B6B-PH-K_1x06_P2.00mm_Vertical
J4: Conn_01x08_Pin; JST_PH_B8B-PH-K_1x08_P2.00mm_Vertical

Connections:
+3.3V: J1.6, J2.6, J3.6, J4.2
/Encoder1_CS: J1.2, J4.6
/Encoder2_CS: J2.2, J4.7
/Encoder3_CS: J3.2, J4.8
/Encoder_MISO: J1.5, J2.5, J3.5, J4.4
/Encoder_MOSI: J1.4, J2.4, J3.4, J4.3
/Encoder_SCK: J1.3, J2.3, J3.3, J4.5
GND: J1.1, J2.1, J3.1, J4.1

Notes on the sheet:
VCC
Encoder 2
CLK
MISO
To Control Board J4
MOSI
Encoder 3
SPI breakout board to encoders
GND
Encoder 1

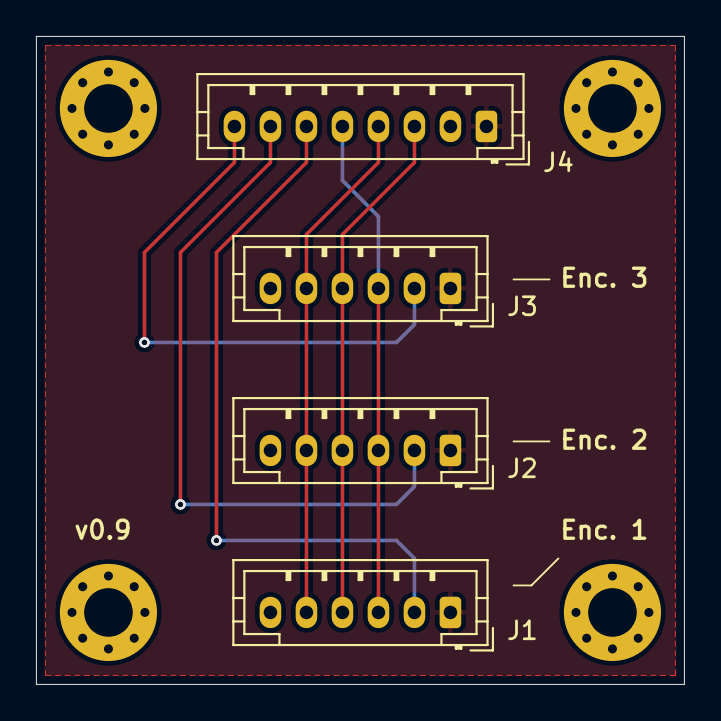
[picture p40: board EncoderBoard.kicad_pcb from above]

Board: 2 copper layers, 36.0 x 36.0 mm, 8 parts (0 on the bottom side), 8 nets.

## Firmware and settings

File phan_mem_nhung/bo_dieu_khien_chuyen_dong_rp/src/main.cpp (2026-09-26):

// --------------------------------------------------------------------------------------
// Project: Tessera
// License: MIT (see LICENSE file for full description)
//          All text in here must be included in any redistribution.
// Maintainer: Tessera project contributors
// --------------------------------------------------------------------------------------

#include "main.h"

#include "hardware/clocks.h"
#include "hardware/pll.h"
#include "hardware/vreg.h"

#include <Wire.h>
#include <algorithm>

#include "robot.h"
#include "tien_ich/logging.h"
#include "tien_ich/frequency_counter.h"
#include "mo_hinh_dong_hoc/kinematic_model_delta3d.h"
#include "version.h"
#include "hw_config.h"
#include "LittleFS.h"

#include "demo_gcode_generator.h"

//*** GLOBALS ***************************************************************************

// NeoPixelConnect strip(PIN_BUILTIN_LED, 1);
Robot robot(0.01f);

/*
MT6835Encoder encoder1(spi0, PIN_ENCODER1_CS);
MT6835Encoder encoder2(spi0, PIN_ENCODER2_CS);
MT6835Encoder encoder3(spi0, PIN_ENCODER3_CS);

TB6612MotorDriver motor_driver1(
  PIN_MOTOR_EN, PIN_M1_PWM_A_POS, PIN_M1_PWM_A_NEG, PIN_MOTOR_PWMAB,
  PIN_MOTOR_EN, PIN_M1_PWM_B_POS, PIN_M1_PWM_B_NEG, PIN_MOTOR_PWMAB
);
TB6612MotorDriver motor_driver2(
  PIN_MOTOR_EN, PIN_M2_PWM_A_POS, PIN_M2_PWM_A_NEG, PIN_MOTOR_PWMAB,
  PIN_MOTOR_EN, PIN_M2_PWM_B_POS, PIN_M2_PWM_B_NEG, PIN_MOTOR_PWMAB
);
TB6612MotorDriver motor_driver3(
  PIN_MOTOR_EN, PIN_M3_PWM_A_POS, PIN_M3_PWM_A_NEG, PIN_MOTOR_PWMAB,
  PIN_MOTOR_EN, PIN_M3_PWM_B_POS, PIN_M3_PWM_B_NEG, PIN_MOTOR_PWMAB
);

ServoController servo_controller1(motor_driver1, encoder1, 400/4);
ServoController servo_controller2(motor_driver2, encoder2, 400/4);
ServoController servo_controller3(motor_driver3, encoder3, 400/4);
FrequencyCounter loop_freq_counter(1000);

PathPlanner planner(0.01f);
MotionController motion_controller(&planner);
Pose6DF current_pose;

CommandParser command_parser; */

//*** FUNCTIONS *************************************************************************

// Run before setup()
//__attribute__((constructor))
void overclock() {
  vreg_set_voltage(VREG_VOLTAGE_1_20);         // For >133 MHz
  busy_wait_us(10 * 1000);  // 10 ms delay
  set_sys_clock_khz(250000, true);             // Set to 250 MHz
}

void set_led_color(uint8_t r, uint8_t g, uint8_t b) {
 /* strip.neoPixelSetValue(0, r, g, b, false);
  delayMicroseconds(2000);
  strip.neoPixelShow(); */
}

void led_blink(uint8_t r, uint8_t g, uint8_t b, int count, int period_time_ms) {
  for(int i=0; i<count; i++) {
    gpio_put(PIN_BUILTIN_LED, 1);
    // set_led_color(r, g, b);
    sleep_ms(period_time_ms/2);
    // set_led_color(0, 0, 0);
    gpio_put(PIN_BUILTIN_LED, 0);
    sleep_ms(period_time_ms/2);
  }
}

void main_core0() {
  uint64_t last_time = time_us_64();

  #ifdef DEMO_MODE
    auto* demo_gcode_generator = new DemoGcodeGenerator(&robot);
    demo_gcode_generator->run();  // blocks forever
  #endif

  while(true) {
    // update motion controller
    robot.update_command_parser();
    robot.update_path_planner();
  }
}

void main_core1() {
  LOG_INFO("Starting servo controll loops on core 1...");

  uint64_t last_time = time_us_64();
  while(true) {
    // get time and detla time
    uint64_t time_us = time_us_64();
    float dt = float(time_us - last_time)*1e-6f;
    last_time = time_us;

    // limit time delta
    dt = std::min(dt, 0.0001f);

    // update servo loops
    robot.update_servo_controllers(dt);
  }
}

void setup() {
  gpio_init(PIN_BUILTIN_LED);
  gpio_set_dir(PIN_BUILTIN_LED, GPIO_OUT);
  
  led_blink(0, 0, 30, 3, 100);
  // stdio_init_all();  // Initializes USB or UART stdio
  overclock();
  // Serial.begin(921600);
  Logger::instance().begin(921600, false);
  #ifndef DEMO_MODE
  while(!Serial);
  #endif

  set_led_color(50, 10, 0);
  // auto* test = new KinematicModel_Delta3D(); test->test(); delete test;

  delay(100);  // Allow time for serial monitor to connect
  
  LOG_INFO("Tessera Firmware: %s", FIRMWARE_VERSION);
  LOG_INFO("System clock: %i Mhz", int32_t(clock_get_hz(clk_sys))/1000/1000);

  // LittleFS.format();
  if (!LittleFS.begin()) {
    LOG_ERROR("Mounting filesystem failed");
  } else {
    FSInfo fs_info;
    LittleFS.info(fs_info);
    LOG_INFO("Mounting filesystem successfully [%i/%i bytes used]", 
             (int)fs_info.usedBytes, (int)fs_info.totalBytes);
  }

  LOG_INFO("Initializing device...");
  robot.init();

  multicore_launch_core1(&main_core1);
  sleep_ms(100);
  
  set_led_color(0, 20, 0);
  LOG_INFO("Initialization finished");
  LOG_INFO(" ");

  gpio_put(PIN_BUILTIN_LED, 1);

  return;

  /*
  rotencoder_wire.setSDA(PIN_ENCODER_SDA);
  rotencoder_wire.setSCL(PIN_ENCODER_SCL);
  rotencoder_wire.begin();
  rotencoder_wire.setClock(1000000);
  encoder.init();
  encoder.set_hysteresis(0x4); //0x6);
  */
}

void loop() {
  main_core0();
}

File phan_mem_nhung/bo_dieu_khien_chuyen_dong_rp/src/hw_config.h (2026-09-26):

#pragma once
#include "tien_ich/math_constants.h"

// #define DEMO_MODE

//--- MOTORS ------------------------------------------------------------------

// motor pole pair count
//  * 100 for 0.9deg stepper motors
//  * 50  for 1.8deg stepper motors
constexpr float MOTOR1_POLE_PAIRS = 50;
constexpr float MOTOR2_POLE_PAIRS = 50;
constexpr float MOTOR3_POLE_PAIRS = 50;

// max current factor in range [0..1]. Lower values reduce pwm resolution so a
// value above 0.4 is recommended.
constexpr float MOTOR_MAX_CURRENT_FACTOR = 0.6f;

//--- ENCODERS ----------------------------------------------------------------

// Conversion factor from encoder angle (one 2pi period every two magnets) to rotor angle.
// Used when the system can not rely on calibration data being present (e.g. during homing)
constexpr float ENCODER_MAGNET_PITCH = 3.0f;    // [mm]
constexpr float ENCODER_MAGNET_RADIUS = 30.0f;  // [mm]
constexpr float ENCODER_ANGLE_TO_ROTOR_ANGLE = (ENCODER_MAGNET_PITCH*2.0f) / 
                                               (ENCODER_MAGNET_RADIUS * Constants::TWO_PI_F);
											   
// enables error checking for encoders (slow) - useful for debugging
// Note: some chips seem to return always a crc of 0 producing massiv false errors       
constexpr bool ENABLE_ENCODER_CRC = false;

//--- HOMING ------------------------------------------------------------------

constexpr float HOMING_VELOCITY   = 1.0f;        // rad per s
constexpr float HOMING_CURRENT    = 0.15f;       // range 0..1
// NOT IMPLEMENTED YET: constexpr float HOMING_FINISH_POS = 0.5f;        // in rad

//--- CALIBRATION -------------------------------------------------------------

// degrees from home position
constexpr float CALIBRATION_RANGE = 83; 

// velocity of the magnetic field during calibration (lower is more accurate)
constexpr float CALIBRATION_FIELD_VELOCITY = 20.0f; 

// size of the calibration lookup table
constexpr int ENCODER_LUT_SIZE = 256;

//--- CLOSED LOOP CONTROL -----------------------------------------------------

// position controller 
constexpr float POS_KP = 60.0f;
constexpr float POS_KI = 30000.0f;

// velocity controller
constexpr float VEL_LOWPASS_TC = 0.004f;
constexpr float VEL_KP = 0.2f;
constexpr float VEL_KI = 90.0f;

//--- KINEMATIC ---------------------------------------------------------------

// Kinematic Parameters are defined kinematic_modes/kinematic_model_delta3d.cpp

// NUM_JOINTS and NUM_TOOLS are defined in 'path_segment.h'. Note that changing
// the number of joints requires changing the kinematic model accordingly and
// also requires the initialization of the correct number of 'RobotJoint' objects
// in the Robtos init method.

//--- PINS --------------------------------------------------------------------

#define JOINT_READY_OVERRIDE

// #define SINGLE_AXIS_BOARD
#ifndef SINGLE_AXIS_BOARD
  // Pins for 3Axis Board
  // #define PIN_BUILTIN_LED 23 // RP2040 pico clone
  // #define PIN_USER_BUTTON 24 // RP2040 pico clone
  #define PIN_BUILTIN_LED 25

  #define PIN_M1_PWM_A_POS  13
  #define PIN_M1_PWM_A_NEG  12
  #define PIN_M1_PWM_B_POS  14
  #define PIN_M1_PWM_B_NEG  15

  #define PIN_M2_PWM_A_POS  9
  #define PIN_M2_PWM_A_NEG  8
  #define PIN_M2_PWM_B_POS  10
  #define PIN_M2_PWM_B_NEG  11

  #define PIN_M3_PWM_A_POS  5
  #define PIN_M3_PWM_A_NEG  4
  #define PIN_M3_PWM_B_POS  6
  #define PIN_M3_PWM_B_NEG  7


  #define PIN_MOTOR_EN      18
  #define PIN_MOTOR_PWMAB   19

  #define PIN_ENCODER1_CS 20
  #define PIN_ENCODER2_CS 21
  #define PIN_ENCODER3_CS 22
  #define PIN_ENCODER_SCK 2
  #define PIN_ENCODER_MISO 0
  #define PIN_ENCODER_MOSI 3

  #define PIN_TOOL1 16
  #define PIN_TOOL2 17

#else
  // Single Axis Board
  #define PIN_BUILTIN_LED 16
  #define PIN_USER_BUTTON 24

  #define PIN_M1_PWM_A_POS  13
  #define PIN_M1_PWM_A_NEG  12
  #define PIN_M1_PWM_B_POS  14
  #define PIN_M1_PWM_B_NEG  15

  #define PIN_M2_PWM_A_POS  9
  #define PIN_M2_PWM_A_NEG  8
  #define PIN_M2_PWM_B_POS  10
  #define PIN_M2_PWM_B_NEG  11

  #define PIN_M3_PWM_A_POS  5
  #define PIN_M3_PWM_A_NEG  4
  #define PIN_M3_PWM_B_POS  6
  #define PIN_M3_PWM_B_NEG  7


  #define PIN_MOTOR_EN      18
  #define PIN_MOTOR_PWMAB   19

  #define PIN_ENCODER1_CS 20
  #define PIN_ENCODER2_CS 21
  #define PIN_ENCODER3_CS 22
  #define PIN_ENCODER_SCK 2
  #define PIN_ENCODER_MISO 0
  #define PIN_ENCODER_MOSI 3
#endif

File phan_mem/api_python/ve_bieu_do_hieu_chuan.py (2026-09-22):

import argparse

import matplotlib.pyplot as plt

from tessera_api import TesseraInterface

plt.rcParams['figure.dpi'] = 200


def plot_calibration_data(ax_encoder_counts, ax_field_angel, label, data):
    # Plot on the provided Axes object
    if ax_encoder_counts is not None:
        ax_encoder_counts.plot(data[0], data[2], label=label)
        ax_encoder_counts.set_xlabel('Motor Angle [rad]')
        ax_encoder_counts.set_ylabel('Encoder Counts Raw')
        ax_encoder_counts.set_title('Encoder Count Plot')
        ax_encoder_counts.legend()
        ax_encoder_counts.grid(True)

    # Plot on the provided Axes object
    if ax_field_angel is not None:
        ax_field_angel.plot(data[0], data[1], label=label)
        ax_field_angel.set_xlabel('Motor Angle [rad]')
        ax_field_angel.set_ylabel('Motor Field Angle [rad]')
        ax_field_angel.set_title('Field Angle Plot')
        ax_field_angel.legend()
        ax_field_angel.grid(True)


def list_available_ports():
    devices = TesseraInterface.enumerate_devices()
    if not devices:
        print('No serial devices detected.')
        return devices

    print('Available serial devices:')
    for device in devices:
        print(f"  {device['label']}")

    return devices


def resolve_port(port):
    if port:
        return port

    devices = TesseraInterface.enumerate_devices()
    pico_devices = [device for device in devices if 'pico' in device['label'].lower()]

    if len(pico_devices) == 1:
        print(f"Using detected Pico serial device: {pico_devices[0]['label']}")
        return pico_devices[0]['port']

    if len(pico_devices) > 1:
        print('Multiple Pico serial devices detected. Pass --port to choose one:')
        for device in pico_devices:
            print(f"  {device['label']}")
        raise SystemExit(1)

    if len(devices) == 1:
        print(f"Using detected serial device: {devices[0]['label']}")
        return devices[0]['port']

    if devices:
        print('Multiple serial devices detected. Pass --port to choose one:')
        for device in devices:
            print(f"  {device['label']}")
    else:
        print('No serial devices detected.')

    raise SystemExit(1)


def parse_args():
    parser = argparse.ArgumentParser(
        description='Run joint calibration and plot the measured data.',
    )
    parser.add_argument(
        '--port',
        help='Serial port to use (for example /dev/ttyACM0 or COM3).',
    )
    parser.add_argument(
        '--list-ports',
        action='store_true',
        help='List detected serial devices and exit.',
    )
    return parser.parse_args()


def main():
    args = parse_args()
    if args.list_ports:
        list_available_ports()
        return

    port = resolve_port(args.port)
    tessera = TesseraInterface(show_communication=True, show_log_messages=True)
    if not tessera.connect(port):
        raise SystemExit(f'Could not connect to {port}.')

    try:
        # Create subplots
        fig, ax = plt.subplots(1, 1, figsize=(10, 7), sharex='all')

        for i in range(3):
            _, data = tessera.calibrate_joint(i, save_result=False)
            plot_calibration_data(ax, None, f'Actuator {i}', data)

        # Adjust layout and show
        plt.tight_layout()
        plt.show()
    finally:
        tessera.disconnect()


if __name__ == '__main__':
    main()

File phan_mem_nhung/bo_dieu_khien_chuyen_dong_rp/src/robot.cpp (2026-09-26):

// --------------------------------------------------------------------------------------
// Project: Tessera
// License: MIT (see LICENSE file for full description)
//          All text in here must be included in any redistribution.
// Maintainer: Tessera project contributors
// --------------------------------------------------------------------------------------

#include <LittleFS.h> 
#include "robot.h"
#include "hw_config.h"
#include "tien_ich/logging.h"
#include "tien_ich/utilities.h"
#include "mo_hinh_dong_hoc/kinematic_model_delta3d.h"
#include "dieu_khien_servo/homing_controller.h"
#include "dieu_khien_servo/actuator_calibration.h"
#include "khop_robot/robot_joint.h"
#include "pico/multicore.h"
#include "version.h"
#include "dung_cu_robot/pwm_tool.h"

constexpr int SPINLOCK_ID_SHARED_DATA = 0;
constexpr int SPINLOCK_ID_JOINTS = 1;

#include <NeoPixelConnect.h>
NeoPixelConnect led(PIN_BUILTIN_LED, 1);

//*** FUNCTION **************************************************************************

bool startswith(const std::string& str, const std::string& prefix) {
    return str.size() >= prefix.size() &&
           std::equal(prefix.begin(), prefix.end(), str.begin());
}

//*** CLASS *****************************************************************************

//--- Robot -----------------------------------------------------------------------------

Robot::Robot(float path_segment_time_step) : 
  path_planner(nullptr, path_segment_time_step), 
  motion_controller(&path_planner),
  servo_loop_frequency_counter(10000),
  motion_controller_frequency_counter(1000),
  shared_data(SPINLOCK_ID_SHARED_DATA),
  joints_spin_lock(spin_lock_instance(SPINLOCK_ID_JOINTS))
{
  kinematic_model = new KinematicModel_Delta3D();
  path_planner.set_kinematic_model(kinematic_model);

  for(int i=0; i<NUM_JOINTS; i++)
    joints[i] = nullptr;

  command_parser.set_command_processor(this);

  current_feedrate = LinearAngular(10.0f, 1.0f);
  max_acceleration = LinearAngular(500.0f, 50.0f);
  path_buffering_time_us = 50*1e3;

  for(int i=0; i<NUM_TOOLS; i++)
    robot_tools[i] = nullptr;

  state = ERobotState::IDLE;
}

Robot::~Robot() {
  if(kinematic_model != nullptr)
    delete kinematic_model;

  for(int i=0; i<NUM_JOINTS; i++) {
    if(joints[i] != nullptr)
      delete joints[i];
    joints[i] = nullptr;
  }
}

void Robot::init() {
  MT6835Encoder::setup_spi(spi0, PIN_ENCODER_SCK, PIN_ENCODER_MOSI, PIN_ENCODER_MISO, 8000000);

  // axis 1
  {
    auto* encoder = new MT6835Encoder(spi0, PIN_ENCODER1_CS);
    auto* motor_driver = new TB6612MotorDriver(
      PIN_MOTOR_EN, PIN_M1_PWM_A_POS, PIN_M1_PWM_A_NEG, PIN_MOTOR_PWMAB,
      PIN_MOTOR_EN, PIN_M1_PWM_B_POS, PIN_M1_PWM_B_NEG, PIN_MOTOR_PWMAB
    );
	encoder->set_crc_enabled(ENABLE_ENCODER_CRC);
    joints[0] = new RobotJoint(encoder, motor_driver, MOTOR1_POLE_PAIRS);
  }

  // axis 2
  {
    auto* encoder = new MT6835Encoder(spi0, PIN_ENCODER2_CS);
    auto* motor_driver = new TB6612MotorDriver(
      PIN_MOTOR_EN, PIN_M2_PWM_A_POS, PIN_M2_PWM_A_NEG, PIN_MOTOR_PWMAB,
      PIN_MOTOR_EN, PIN_M2_PWM_B_POS, PIN_M2_PWM_B_NEG, PIN_MOTOR_PWMAB
    );
	encoder->set_crc_enabled(ENABLE_ENCODER_CRC);
    joints[1] = new RobotJoint(encoder, motor_driver, MOTOR2_POLE_PAIRS);
  }

  // axis 3
  {
    auto* encoder = new MT6835Encoder(spi0, PIN_ENCODER3_CS);
    auto* motor_driver = new TB6612MotorDriver(
      PIN_MOTOR_EN, PIN_M3_PWM_A_POS, PIN_M3_PWM_A_NEG, PIN_MOTOR_PWMAB,
      PIN_MOTOR_EN, PIN_M3_PWM_B_POS, PIN_M3_PWM_B_NEG, PIN_MOTOR_PWMAB
    );
	encoder->set_crc_enabled(ENABLE_ENCODER_CRC);
    joints[2] = new RobotJoint(encoder, motor_driver, MOTOR3_POLE_PAIRS);
  }

  // initialize axes
  for(int i=0; i<NUM_JOINTS; i++) {
    joints[i]->init(i);
    joints[i]->load_calibration();
  }

  // add tools
  robot_tools[0] = new PwmTool();
  ((PwmTool*)robot_tools[0])->init(PIN_TOOL1, 8000, 8);

  robot_tools[1] = new PwmTool();
  ((PwmTool*)robot_tools[1])->init(PIN_TOOL2, 8000, 8);

  // setup timer for updating the motion controller (which evaluates joint space path
  // segments and produces the current target position for the servo loops)
  float motion_controller_update_time_us = 500;
  add_repeating_timer_us(-motion_controller_update_time_us, 
                         Robot::update_motion_controller_isr, 
                         (void*)this, 
                         &motion_controller_update_timer);
}


void Robot::update_command_parser() {
  // process serial input
  if (Serial.available()) {
    char c = Serial.read();
    command_parser.add_input_character(c);
    // Serial.write(c);
  }

  // update command parse which will queue command to the path planner
  command_parser.update();

  // TESTING:
  //sleep_ms(10);
  //float pos_error = joints[1]->servo_controller->get_position_error();
  //LOG_INFO(">pos_error [Âµrad]: %f\n", pos_error*1e6);
  //Serial.printf(">pos_error [Âµrad]: %f\n", pos_error*1e6);#
  //LOG_INFO(">pos_x [mm]: %f", joints[1]->position);
  //update_servo_controllers(0.01f);
}

/**
 * Updates the path planner, that chops up kartesian path segments into joint space
 * path segments using the inverse kinematic model. It then enqueues these joint space path
 * segments for the motion controller.
 */
void Robot::update_path_planner() {
  // check if buffering starts
  uint64_t time = time_us_64();
  if(state == ERobotState::IDLE && path_planner.input_queue_size() > 0) {
    state = ERobotState::BUFFERING_PATH;
    path_buffering_start_time = time;
  }

  // check if execution starts
  uint64_t buffering_time = time-path_buffering_start_time;
  if(state == ERobotState::BUFFERING_PATH && buffering_time > path_buffering_time_us) {
    state = ERobotState::EXECUTING_PATH;
  }

  // execute path
  if(state == ERobotState::EXECUTING_PATH) {
    // update planner and generate joint space path segments
    path_planner.process(true);

    if(path_planner.all_finished())
      state = ERobotState::IDLE;
  }
}
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

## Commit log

2026-09-26 update ten du an
    [Assembly_Actuator.FCStd, Assembly_MicroManipulator.backup.FCStd, MotorHorn.FCStd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]
2026-09-26 doi ten thu muc
    [Assembly_Actuator.FCStd, Assembly_BallJointPlate.FCStd, Assembly_EndEffector.FCStd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]
